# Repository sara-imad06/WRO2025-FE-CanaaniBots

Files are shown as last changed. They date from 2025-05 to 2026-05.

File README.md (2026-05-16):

# 📄 Table of contents
### [Our journey](#our-journey)
### [Our plan and Strategy](/our_plan_and_strategy.md)
### [Hardware documentation](/schemes/README.md)
### [Software documentation](/src/README.md)
### [Videos](/video/video.md)
### [Team Photos](/t-photos/)
### [Vehicle Photos](/v-photos/)

## The team yy
From Palestine, we are CanaaniBots — a team of three passionate young engineers and a supportive coach. After a year of competing together in WRO, trying out categories like Innovators and Future Engineers. This year, we're thrilled to return to the Future Engineers challenge once again!

>Members

- **Sara Abdou** from [Birzeit University](https://www.birzeit.edu/en) - Department of Electrical and Computer Engineering, Birzeit UNI
  - imadsara117@gmail.com
- **Rama Najjar** from [Birzeit University](https://www.birzeit.edu/en) - Department of Mechanical and Mechatronics Engineering, Birzeit UNI
  - ramanajjar25@gmail.com
- **Sadeel Taleeb** from [Birzeit University](https://www.birzeit.edu/en) - Department of Electrical and Computer Engineering, Birzeit UNI
  - sadeeltaleeb4@gmail.com

>Coach

- **Eng. Ahmad AbuBaker** - TA at the Mechanical and Mechatronics Engineering Department, Birzeit UNI,[Birzeit University](https://www.birzeit.edu/en/study/academic-departments/mmed)
  - ahmadabubaker199@gmail.com

## Past experiences
Over the past few years, our team has gained a wide range of skills and hands-on experience through continuous work in robotics projects and challenges. These experiences provided us with a strong foundation that we were able to carry into the Future Engineers category, several of our previous learnings remained valuable, such as:
Familiarity with various sensors, including gyroscope and ultrasonic sensors, as well as car steering mechanisms

  - Programming experience, including building our own frameworks
  - Developing visual debugging systems to test and refine our code
  - Hands-on experience with microcontrollers such as Raspberry Pi and Arduino
  - A solid background in working with different programming languages, sensors, and motors
  - Experience using OpenCV libraries for image processing and computer vision

## What the Robot Taught Us
Designing our robot was more than just building hardware—it was a full-on engineering adventure. Every challenge we faced pushed us to learn new tools, experiment with ideas, and grow as a team. From the first sketch to the final test run, the journey was packed with hands-on learning and exciting discoveries, Here are some of the key skills and experiences we gained:
  - Gained experience in mechanical design (learned how to use SolidWorks to design a functional mechanical differential) and prototyping using 3D modeling tools
  - We learned how to design electronic components using Fritzing
  - Explored and implemented advanced steering and turning systems
  - Integrated and calibrated various sensors to ensure accurate and stable robot behavior
  - Practiced debugging techniques and iterative testing to refine performance
  - Improved teamwork, time management, and project planning through collaboration

## Our first design
At first, our initial design was based on a [pre-made metal frame car](https://technolab.ps/detail/471), which included a metal base plate, two additional smaller base parts, a steering system, and four good-quality wheels. We did not rely on the original frame as it was; the main goal of using it was to speed up the design process. We modified it directly using custom parts that we designed and 3D printed, in order to implement the plan we had in mind more accurately and in a way that meets the project’s requirements.

The design phases of the robot were diverse and multi-staged, involving the design of new parts tailored to each stage of the robot’s mechanical development. The design was not static; it evolved continuously based on the requirements of each phase. We also conducted accuracy tests for the robot at each step, according to the strategy we had previously established, to ensure the desired performance and guide adjustments effectively.

All of these stages and modifications were documented in detail in the Hardware Documentation, serving as a clear and comprehensive reference for our work.

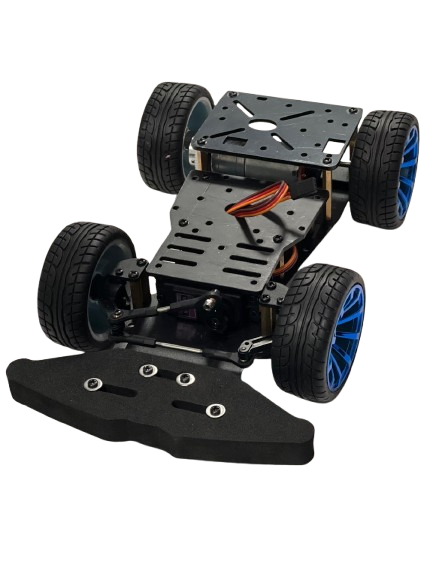
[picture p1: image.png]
pre-made metal frame car
  

## The final design

## Teamwork
We had weekly meetings with our coach to review our progress and make sure we were heading in the right direction. These sessions were essential for reflecting on what we had accomplished, discussing what needed improvement, and going through our documentation to keep everything organized and clear.

Our work was mainly divided into two main parts: mechanical and programming. Each of us focused more on one area depending on our strengths, but we made it a point to collaborate and support each other in both. If someone working on the mechanical side needed help with code, or someone on the programming side needed input on a physical design element, we’d jump in and figure it out together.

Just like our individual team meetings, these coach sessions helped us stay aligned, keep our momentum, and maintain a strong sense of shared responsibility for the entire project.

# Conclusion

# Special thanks
Special thanks to 'Kaksh' for helping us get the components and letting us use the Interface Lab 😊 Your support truly made a difference!
We also extend our heartfelt thanks to Al-Nabali & Al-Faris Co. for their generous financial support and continuous encouragement of our team.

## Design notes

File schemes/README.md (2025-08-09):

# Hardware documentation 
The robot consists of a wide variety of sensors, motors, and two processing units: a Raspberry Pi 5 and an Arduino Mega. The base is built on a 4WD RC Smart Car Robot Chassis with ann MG996R metal servo and bearing kit, which has been heavily modified to suit our project's requirements. These modifications include custom 3D-printed parts, such as a dedicated camera holder and custom spacers, as well as the replacement of several original components to improve stability, wiring, and sensor integration. All engineering modifications are thoroughly documented and clearly illustrated in the guide provided below.

## List of components
We installed a lot of sensors and other components on the car, here is a list of each of them with a link and some additional notes:
- **Base car** [4WD RC Smart Car Robot Chassis](https://technolab.ps/detail/471)
  - originally 248 x 146 mm, 690 g 695.7 g (including DC and servo motor)
- **Steering servo** [MG996R Metal Servo Bearing Kit](https://technolab.ps/detail/471)
- **DC motor** [DC Gear Motor with Encoder](https://roboticx.ps/product/dc-gear-motor-with-encoder/)
  -  Operating voltage 6V, torque 10 kg*cm max power 3.2A, 210 RPM, 341.2 pulse-per-revolution encoder
- **Single Board Computer** [Raspberry Pi 5 4GB](https://roboticx.ps/product/raspberry-pi-5/?asp_highlight=raspberry&p_asid=3)
  - Operating voltage 5V/5A USB-C, 4 USB ports, 40 pins
- **Microcontroller Arduino Mega 2560** [arduino](https://roboticx.ps/product/arduino-mega-2560-r3-china/)
  - Operating voltage 7-12V, 54 Digital I/O Pins (14 PWM outputs)- 16 Analog Inputs, dimensions: 101.5 x 53.3 mm
- **Motor driver** [L298N](https://roboticx.ps/product/dual-motor-controller-module-l298n/)
  - Max Drive current 2A, control voltage 4.5~5.5V
- **Battery**
  - Bundled with car, 4.2V, 5000mAh,Lithium, [Lithium Ion Battery](https://roboticx.ps/product/lithium-ion-battery-18650-cell-5000mah/)
- **Lithium Battery Charger Module**
  - Maximum current can be 5A , Output voltage 5V
- **Power switch** [SPST](https://roboticx.ps/product/rocker-switch-on-off-spst/)
- **Laser sensor x3** [VL53L0XV2 Laser](https://roboticx.ps/product/vl53l0xv2-laser-ranging-sensor-time-of-flight-tof/)
  - Dimensions 25 x 10 x 4 mm, 50mm – 1.2m range (default mode), 50mm – 2.2m range (long range mode), frequency 5-33 Hz, accuracy ±2cm ,3.3V
- **Camera** [Raspberry Pi Camera Module V2](https://roboticx.ps/product/raspberry-pi-camera-module/?asp_highlight=raspberry&p_asid=3)
  - No built-in color detection algorithm, field of View: 62.2° horizontal 48.8° vertical, up to 90 fps
- **IMU** [GY-BN008X](https://technolab.ps/products?search=bno)
  - Inertial Measurement Unit (IMU) BNO085 – operates at 3.3V with a gyro drift of about 0.5°/min and a dynamic rotation error of approximately 4.5°

## Sensors and motors communication protocols
The different communication protocols used between the components of the robot and their hierarchy:
- Computer
  - Raspberry Pi `SSH & VNC & micro-HDMI `
    - Ardunio Maga `USB `
      - DC Motor with endcoder `Interrupt`
      - Motor driver `PWM` 2x`Digital`
      - Servo `PWM`
      - 3x VL53L0X Sensor `I2C` + `Digital Output (XSHUT)`
  - Camera `CSI-2`

## Design and 3D Printing Of Parts and Assembly Instructions
All parts were specifically designed for the competition using SolidWorks and printed on Qidi i-Fast, Flsun V400, and Flashforge Adventurer 4 Pro printers using a slicer. The files were exported in (.stl) format for 3D printing, and the material used was PLA, The Flashforge Adventurer 4 Pro was mainly used for testing parts, as its print quality was not sufficient for final components. Once the designs were confirmed through testing, the Qidi i-Fast and Flsun V400 were used to print the final parts due to their higher speed and accuracy. You can view the designs of all parts in SLDASM and SLDPRT formats [here](/models/Solid_Works_3D_Drawings),we drilled and adjusted all the parts ourselves in the engineering workshops at the university.

### 1. Level one: Initial Kit-Based Structure and Custom Stage Planning
We started the mechanical build using individual parts from a kit, which included a steering system, a servo motor, and a DC motor. These components were assembled to create a basic driving platform suitable for the project’s initial requirements. Only the first stage of the kit was used, as it provided the base needed for steering and driving tests. The second stage was excluded. 

After initial assembly and testing, we decided to design a complete custom robot structure that better fit the competition dimensions and the hardware requirements. The first concept design was sketched directly on a photo of the assembled parts to visualize the planned structure. The design features a three-stage stacked layout, with all stages planned for 3D printing and optimized for height and component placement.

The first stage, reused from the kit, holds the servo motor and steering system at the front and the DC motor at the rear. The battery pack was placed in the center of this stage to keep the center of mass low, which improves traction between the wheels and the mat and increases stability during movement. This decision was based on advice from our coach, who recommended placing heavier components closer to the ground.

The second stage is designed to hold the Arduino Mega, the motor driver, and three distance sensors — one at the front, one on the left, and one on the right. The sketch originally labeled these as ultrasonic sensors, but they were later replaced with laser sensors after design finalization. This stage also includes space for organized cable routing and clean sensor alignment.

The third stage is reserved for the Raspberry Pi, which was placed at the top of the robot due to its higher heat output compared to the other components. Positioning it on the upper stage improves passive cooling. The design also includes a camera mount fixed to the front of the first stage, providing a stable and forward-facing view for image capture.
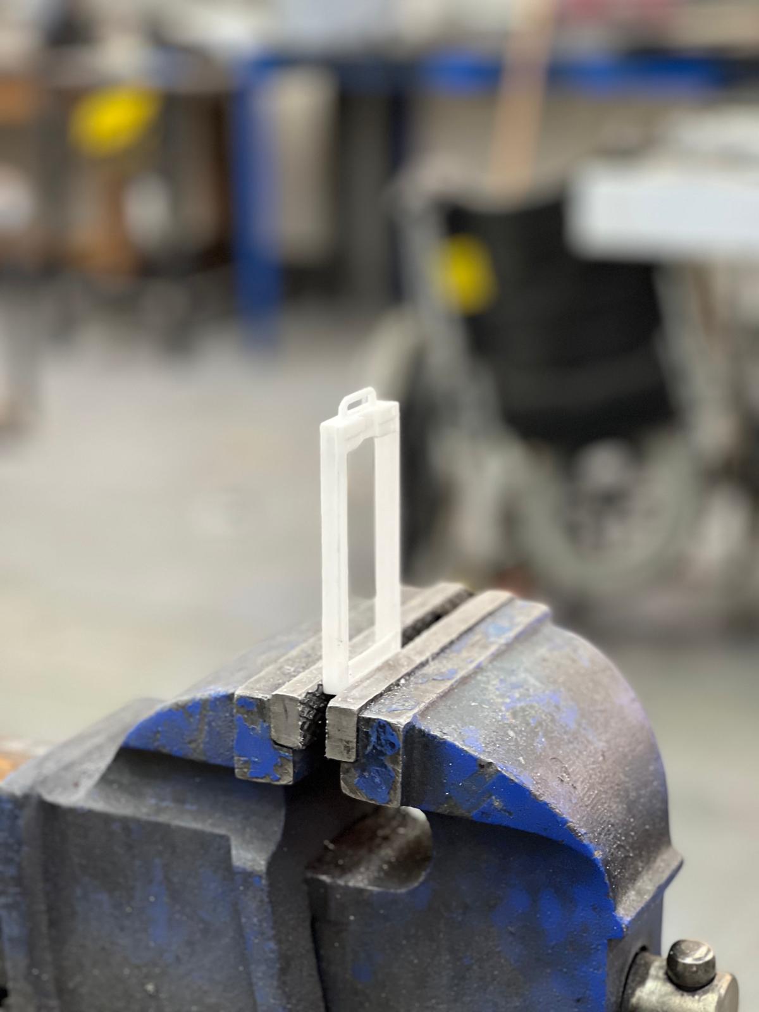
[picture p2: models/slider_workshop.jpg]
Slider


### 2. Level two: Mechanical Calibration for Straight-Line Stability
At this stage, the focus shifted to calibrating the robot’s mechanical movement to ensure it drives in a perfectly straight line without deviation. To achieve this, we designed and manufactured a set of calibration tools consisting of pen holders, created using SolidWorks and printed in PLA using 3D printers. These holders were mounted at the front and rear of the robot chassis and used as a simple tool to verify mechanical alignment.

Each holder includes a vertical opening designed to securely hold a pen. When the robot is placed on a flat surface and moves forward, both pens draw lines. The goal is for the two lines to perfectly overlap, which confirms that the robot is moving in a straight line. If there is any separation or misalignment between the lines, it indicates a deviation in the robot’s path. In such cases, we measured the offset and documented it, allowing us to later apply software-based corrections without the need for mechanical redesign.

During testing, we encountered an issue where the pen openings were too tight, preventing the pens from fitting properly. To solve this, we manually widened the holes using drilling tools in the university’s engineering workshops. This adjustment ensured the pens fit correctly and that the calibration tool functioned reliably, producing consistent and accurate results.

### 3. Level three:

### 4. Level four: 

### 5. Level five:

## Assembly
We encountered several challenges during the assembly and planning process, but we are very proud of the work we have accomplished. If you have any questions or encounter any issues, please don't hesitate to contact us at ramanajjar25@gmail.com(Rama) or ahmadabubaker199@gmail.com(Ahmad) through any preferred method.

## Wiring diagrams and details
### 1. Adjusting the servo motor angle  
[Wiring](/schemes/wiring_1.fzz)

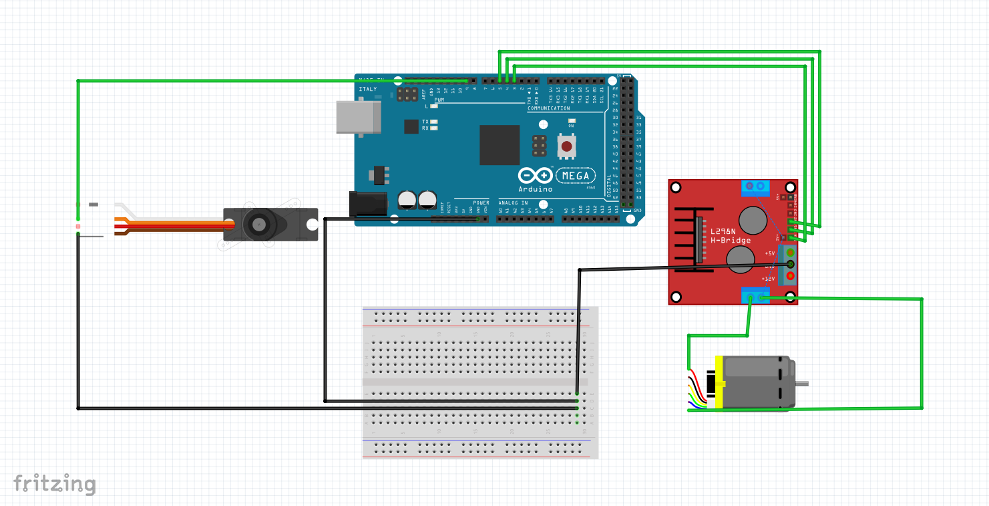
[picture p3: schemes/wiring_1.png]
Stage 1


#### Wiring details at this stage
**DC Motor via L298N Module**  
(Connected to pins 3, 4, and 5)  
L298N to Arduino Mega:
- IN1 → Pin 4 (controls motor direction)
- IN2 → Pin 5 (controls motor direction)
- ENA → Pin 3 (PWM pin, controls motor speed)

L298N Power:
- OUT1 & OUT2 → Connect to DC motor wires
- 12V / VCC → Connect to external power supply (6V–12V battery)
- GND → Connect to Arduino GND
- 5V (if jumper is present) → Optional; powers logic (you can use it if your battery is strong enough)

---
**Servo Motor (Steering)**  
(Connected to pin 9)  
Servo Motor to Arduino Mega:
- Signal (usually orange or yellow) → Pin 9
- VCC (red) → External 5V–6V power source
- GND (brown/black) → Connect to common GND with Arduino

Note: Servo motors need a separate power supply if they draw significant current. Always connect the grounds together (Arduino GND and power source GND).

---
### 2. Connecting Arduino Mega with DC Motor Encoder and Servo Motor 
[Wiring diagram](/schemes/test_1_wiring.fzz)

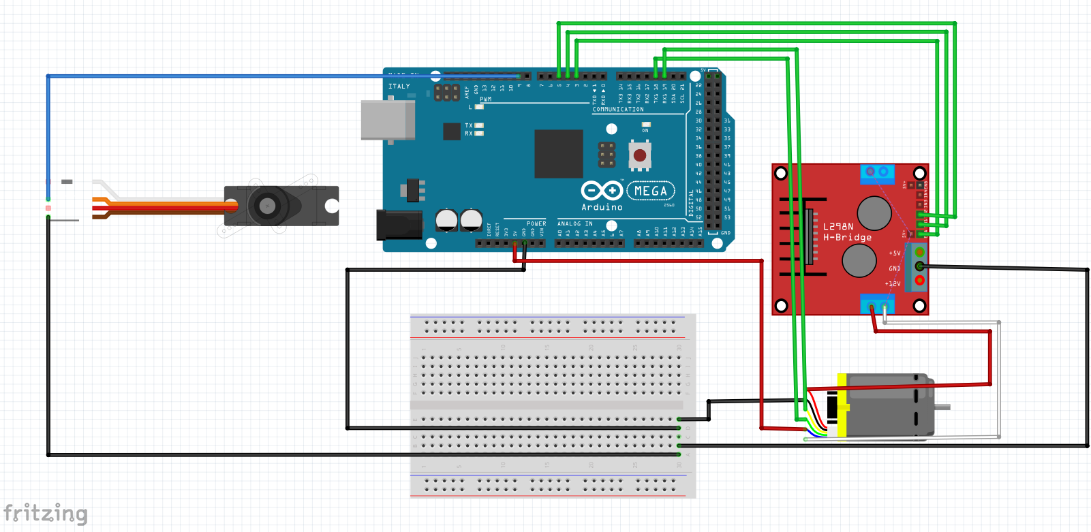
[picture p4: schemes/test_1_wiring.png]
wiring


#### Wiring details at this stage
**L298N Motor Driver to Arduino Mega**
- OUT1 → Red wire of the DC motor
- OUT2 → White wire of the DC motor
- ENA → Pin 3 on Arduino Mega (PWM control)
- IN1 → Pin 4 on Arduino Mega
- IN2 → Pin 5 on Arduino Mega
- GND → GND (to Arduino GND and battery GND)
- 12V → External power (6V–12V battery)

---
**DC Motor Encoder**
- Green (A signal) → Arduino Mega Pin 18 (Interrupt)
- Yellow (B signal) → Arduino Mega Pin 19 (Interrupt)
- Blue (VCC) → Arduino 5V
- Black (GND) → Arduino GND

---
**Servo Motor to Arduino Mega**
- Signal (Orange) → Pin 9 on Arduino Mega
- VCC (Red) → External 5V–6V power source 
- GND (Brown) → Common GND (Arduino GND + battery GND)

---
**Power Connections**
- DC Motor → Powered by external source (6V–12V) through L298N
- Servo Motor → Separate regulated 5V–6V source (e.g., 2S LiPo with voltage regulator)
- Arduino Mega → Powered via USB or VIN (7V–12V regulated input)

### 3. Connecting 3x VL53L0X Sensors and red LED
[Wiring diagram](/schemes/sensors_wiring.fzz)

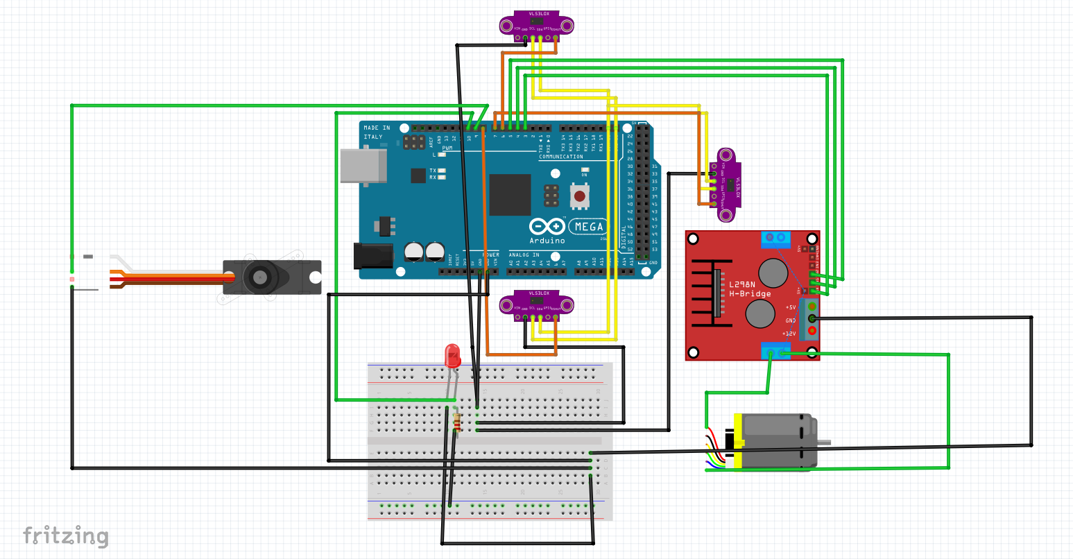
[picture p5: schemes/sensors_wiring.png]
wiring


#### Wiring details at this stage
**Left VL53L0X Sensor**
- VIN → 5V
- GND → GND
- SDA → Arduino Mega Pin 20
- SCL → Arduino Mega Pin 21
- XSHUT → Arduino Mega Pin 6
---
**Front VL53L0X Sensor**
- VIN → 5V
- GND → GND
- SDA → Arduino Mega Pin 20
- SCL → Arduino Mega Pin 21
- XSHUT → Arduino Mega Pin 7
---
**Right VL53L0X Sensor**
- VIN → 5V
- GND → GND
- SDA → Arduino Mega Pin 20
- SCL → Arduino Mega Pin 21
- XSHUT → Arduino Mega Pin 8
---
**Red LED**
- Anode (long leg) → Arduino Pin 10 (with a 220Ω resistor in series)
- Cathode (short leg) → GND (common ground with Arduino)

## Power
## Mechanical methods
workshop details will be here
## Conclusion

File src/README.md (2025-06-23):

# Software documentation 
This document aims to present all the software solutions we have developed—whether through experiments, testing, or iterative development—leading up to the final software implementation. It also outlines the logic and methodology we used to analyze and solve the project challenges by breaking them down into their simplest components.

The system relies primarily on the Raspberry Pi 5, which functions as the "brain" of the robot. It is mainly responsible for analyzing and processing images captured by the camera, utilizing Computer Vision (CV) techniques, as well as Machine Learning (ML) and Artificial Intelligence (AI) to enable the robot to make intelligent decisions based on visual and environmental data.

In parallel, the system includes an Arduino Mega, which serves as the main controller for all motor operations and directional control. It executes movement commands received from the Raspberry Pi and directly manages the DC motors, servos, and motor driver modules to ensure accurate and responsive navigation.

## Components and Connections Simulation
We designed and modified these parts to match the needs of our WRO project, using Fritzing based on our specific requirements. The design process was guided by our strategy of fully simulating all components, connections, and code before implementation. Therefore, creating these parts was an essential step in our plan to ensure a smooth transition from theoretical design to practical application[Parts](https://github.com/sara-imad06/WRO-Designed-Components.git),these parts were created as part of the software work to support the hardware work and make it easeir, and all components and their uses can be found in the Hardware Documentation.

## Visualizer 

## Programming computer & Code editor
This can be either a laptop or a PC. We tested everything on a laptop running Windows 11.We used Visual Studio Code [VScode](https://code.visualstudio.com/download), we used several extinstions like :[Python](https://marketplace.visualstudio.com/items?itemName=ms-python.python), [Ardunio](https://marketplace.visualstudio.com/items?itemName=lintangwisesa.arduino),[Ardunio](https://marketplace.visualstudio.com/items?itemName=moozzyk.Arduino), [Java](https://marketplace.visualstudio.com/items?itemName=SonderMX.java-kits)

You need to install Python on your device with a version that is compatible with your system. We also installed some specific Python libraries:
`pip install pyserial`<br>
`pip install numpy matplotlib`<br>

## Coding Langueges 
At the beginning of the development process, we used Java during the testing phase to experiment with and verify individual code segments. Once we confirmed that each part was working correctly, we assembled the [full code]() in C++, incorporating some C-based syntax and functions, as it is faster and easier to work with when controlling the Arduino and its motors. 

For the Raspberry Pi 5, the code was written in Python, which is the most suitable and widely supported language for working with cameras and communicating with the Pi. To enable communication between the Raspberry Pi (running Python) and the Arduino (running C++), we implemented a [communication code]() over a USB serial connection.

## Arduino Mega
The [Arduino Integrated Development Environment](https://www.arduino.cc/en/software/)  was our choice to develop our first stage (testing code) files were in**file.ino** extinstion. In later stages we moved into VS code.

## Raspberry Pi 5
## Testing Code 
At this stage, we developed an experimental code based on the basic wiring, with the main goal of testing all wheels, motors, and controllers. This stage was divided into three main parts:

### 1. Adjusting the servo motor angle
During this process, the center angle was set to 90 degrees, with a deviation range of ±10 degrees  
[Code](/src/servo_test_code.java)
``` Java
int centerAngle = 90;
int maxDeviation = 10; 

 void turn(int degreesFromCenter) {
    degreesFromCenter = constrain(degreesFromCenter, -maxDeviation, maxDeviation);
    servo.write(centerAngle + degreesFromCenter);
```

#### Classes  
`DCMotor`  
To control the motor speed and direction.

`Steering`  
To control the servo angle with limits.  
`Steering` is currently empty — to add automatic or manual control later.

---

### 2. Working on it simultaneously with the mechanical aspect
The DC motor runs continuously forward, while the servo automatically turns every 5 seconds in a loop: Left → Center → Right → repeat.  
[Code](/src/test.java)

#### Functions  
`setup()`  
Initializes motor and servo pins, starts forward movement, centers the servo, and begins Serial communication.

`loop()`  
Repeatedly changes the steering direction every 5 seconds and prints the current state to the Serial Monitor with center angle = 90, Max to Right = 125, Max to Left = 55.

### 3.
### 4. 

## Open challenge
## Obstacle challenge
## Framework - functions

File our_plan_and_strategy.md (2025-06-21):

# Plan and Strategy
This whole experience felt like a big adventure full of late nights, questions, research, mistakes, and wins. We're really thankful for such a lovely opportunity!
## Principles
- **Be accurate**
- **Be creative**
- **Google your smartest teammate :)**
- **Ask everyone**
- **Be Brave and Open to try**

  ## Ideas
- We excluded the ultrasonic sensor because it takes a long time to respond, making it relatively slow and less accurate. Additionally, when turning at a 90-degree angle, it may return incorrect values, as it reports the nearest distance rather than the parallel one.
- We did not use the color sensor because its readings change with varying lighting conditions, and it needs to be very close to the object to provide accurate values.
- We opted for sensors that rely on laser light transmission technology because they offer relatively higher accuracy,and they provide an approximate measurement of the distance between the robot and the opposing objects in an almost parallel alignment.
- Speed is important, but what matters more is accomplishing the required task with high accuracy first, and then increasing the speed.
- Mechanical calibration is indeed very important; ensuring minimal deviation from a straight path is essential.
- All sensors collect data to accurately determine the robot's position; the key to the solution always lies in measuring distances and pinpointing the robot's location.
- A strong framework is incredibly valuable, it significantly simplifies the process of tackling challenges.

## Strategy

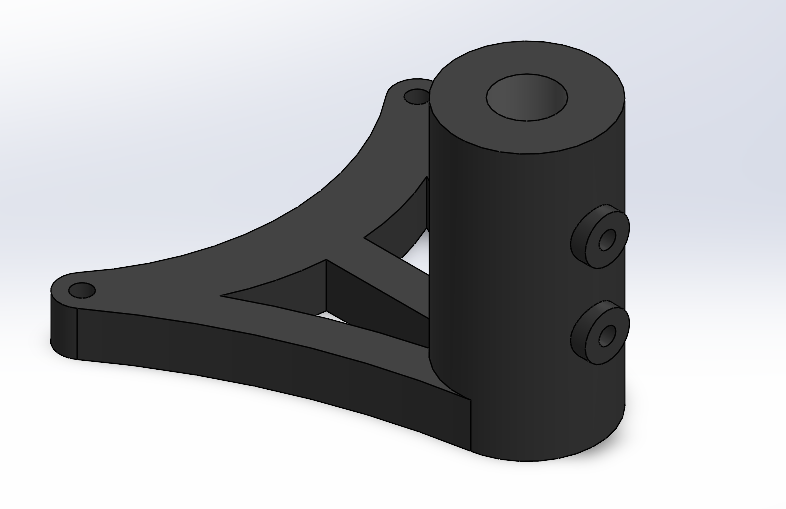
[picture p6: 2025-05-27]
models/Front Pen Holder ISO.png

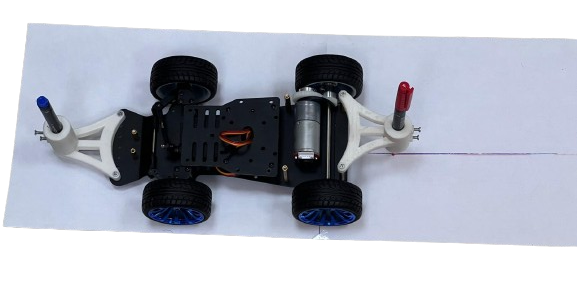
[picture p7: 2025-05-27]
models/stage_1.png

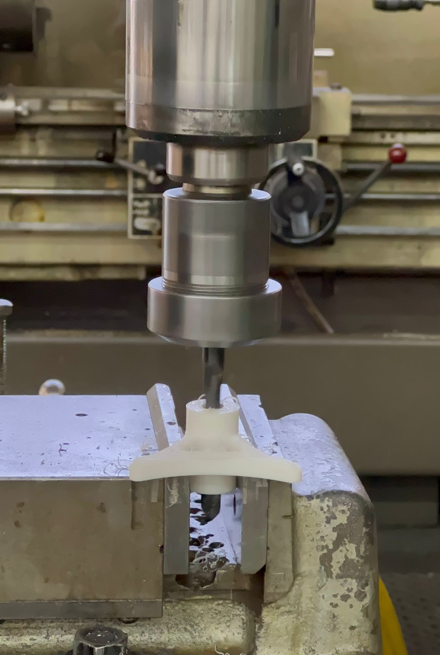
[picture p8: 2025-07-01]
models/Workshop 2.jpg

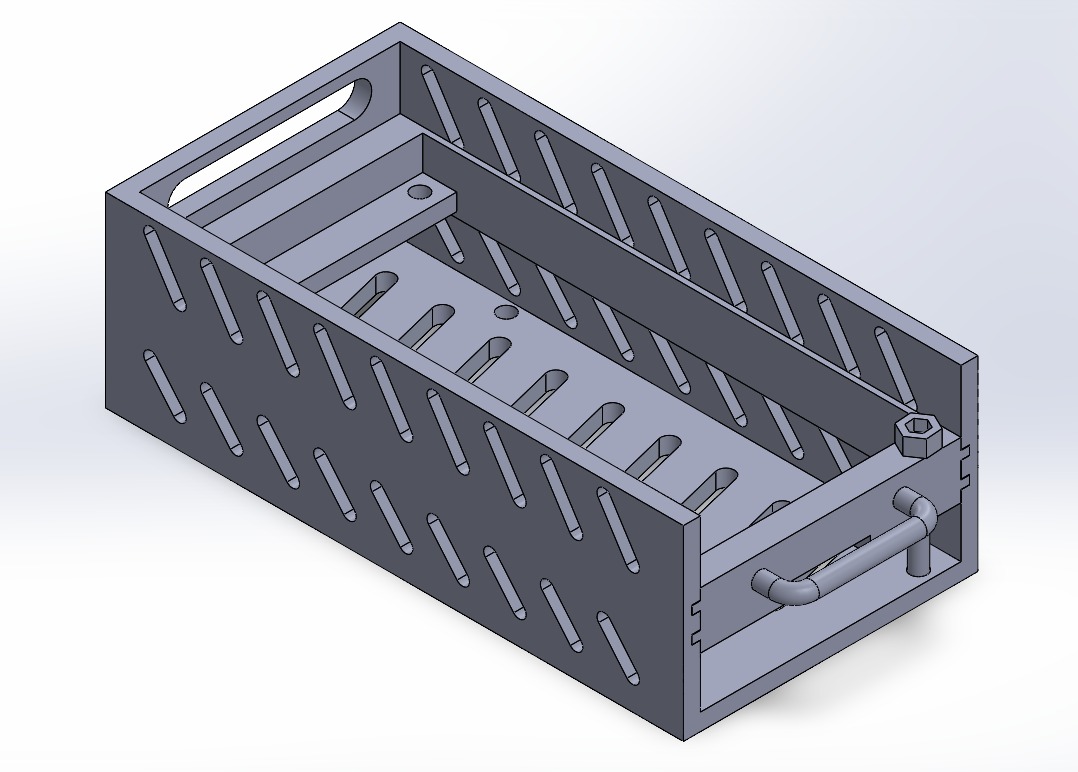
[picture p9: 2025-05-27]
models/Slider.jpg

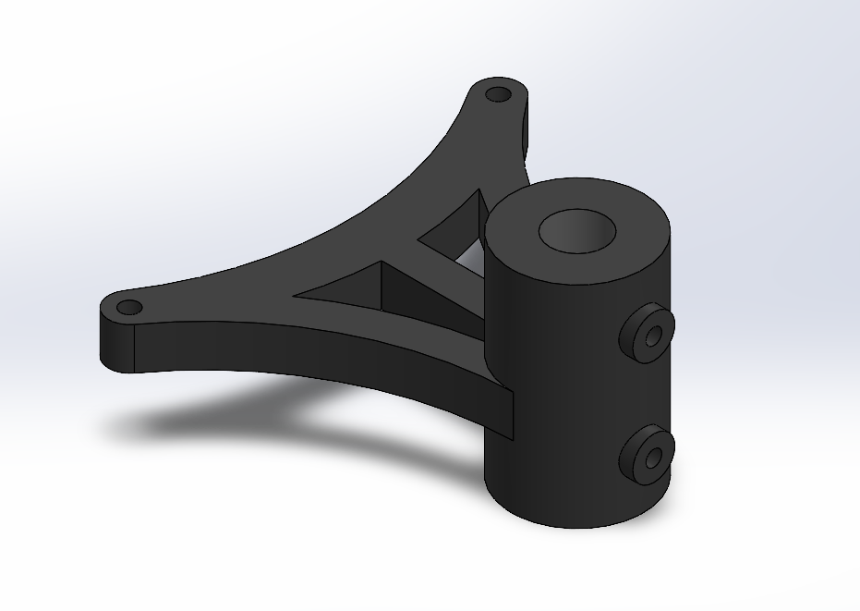
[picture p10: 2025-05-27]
models/Rear Pen Holder ISO.png

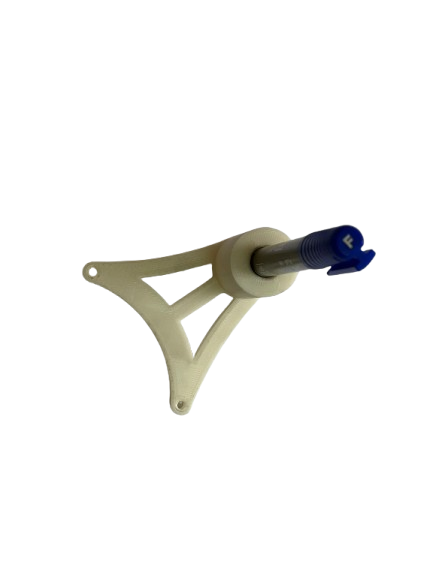
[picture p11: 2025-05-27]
models/pin_holder.png

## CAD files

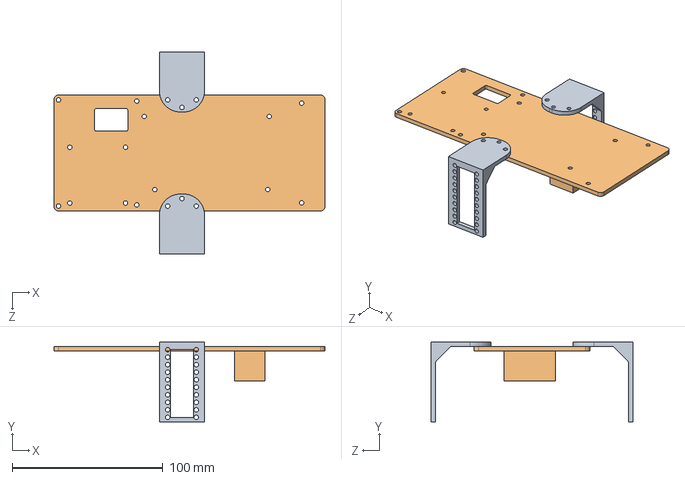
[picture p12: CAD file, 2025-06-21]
models/Solid_Works_3D_Drawings/VOF Assem.SLDASM
180.0 x 53.0 x 134.0 mm
Stage 2 base
TOF holder x 2

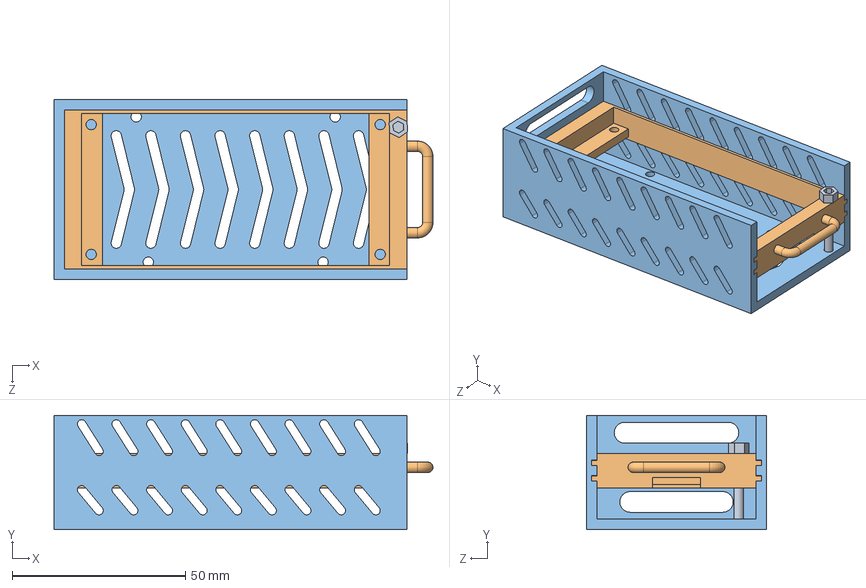
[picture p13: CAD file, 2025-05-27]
models/Solid_Works_3D_Drawings/Assem.SLDASM
109.5 x 33.0 x 52.0 mm
base
slotded cabin
screw

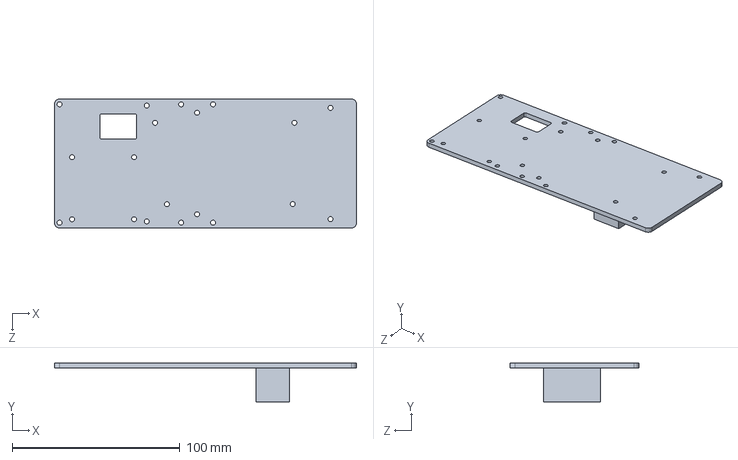
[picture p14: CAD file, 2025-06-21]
models/Solid_Works_3D_Drawings/Stage 2 base.SLDPRT
180.0 x 23.0 x 77.0 mm

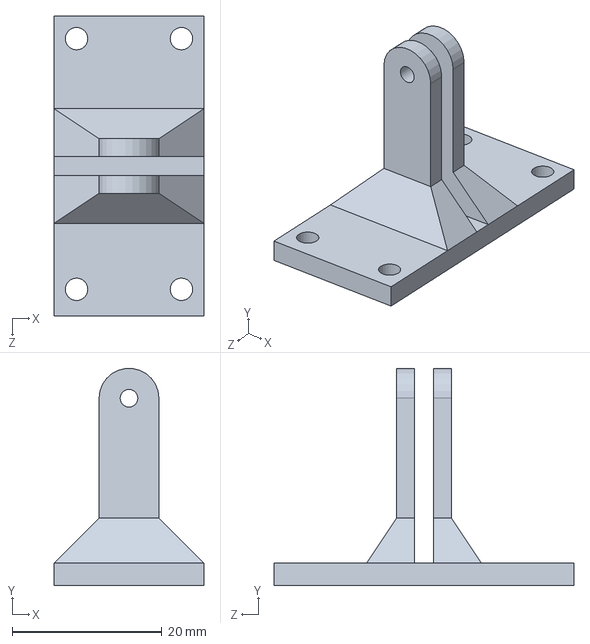
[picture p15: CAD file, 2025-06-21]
models/Solid_Works_3D_Drawings/camera Top holder.SLDPRT
20.0 x 29.0 x 40.0 mm

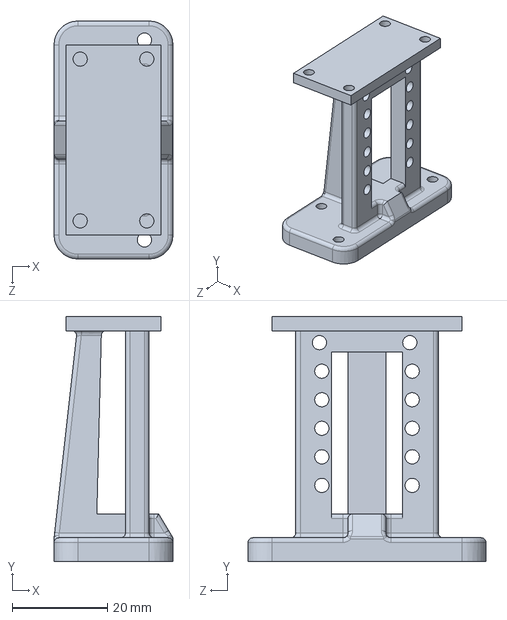
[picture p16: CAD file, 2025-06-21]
models/Solid_Works_3D_Drawings/camera and front TOF base holder.SLDPRT
25.0 x 51.5 x 50.0 mm

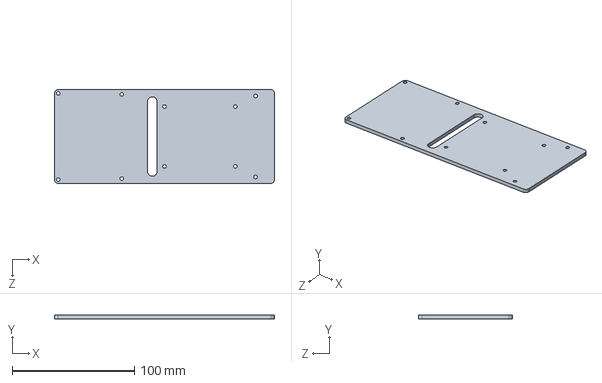
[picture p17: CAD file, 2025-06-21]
models/Solid_Works_3D_Drawings/Stage 3 base.SLDPRT
180.0 x 3.00 x 77.0 mm

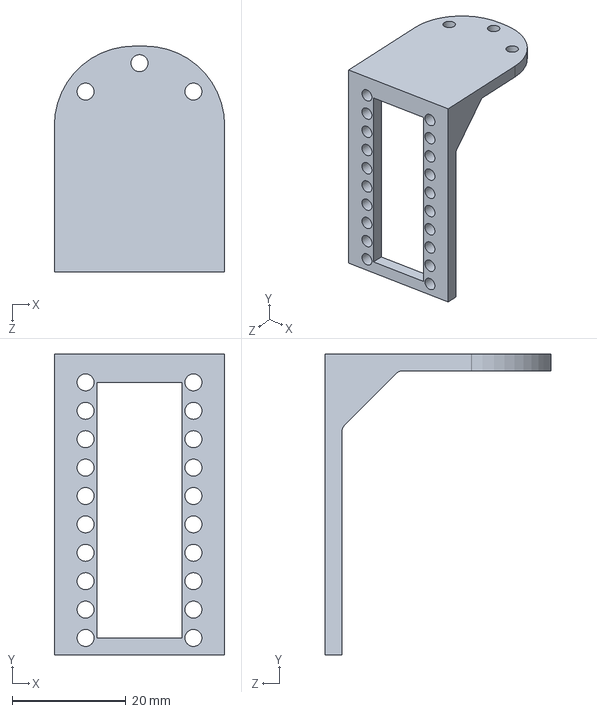
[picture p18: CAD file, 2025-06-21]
models/Solid_Works_3D_Drawings/TOF holder.SLDPRT
30.0 x 53.0 x 39.8 mm

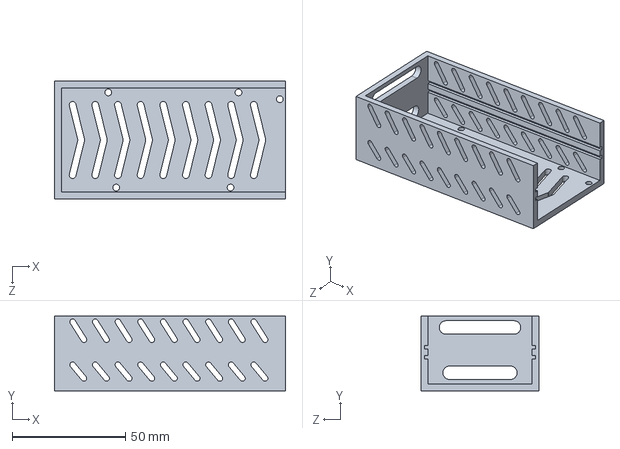
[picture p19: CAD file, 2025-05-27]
models/Solid_Works_3D_Drawings/base.SLDPRT
102.0 x 33.0 x 52.0 mm

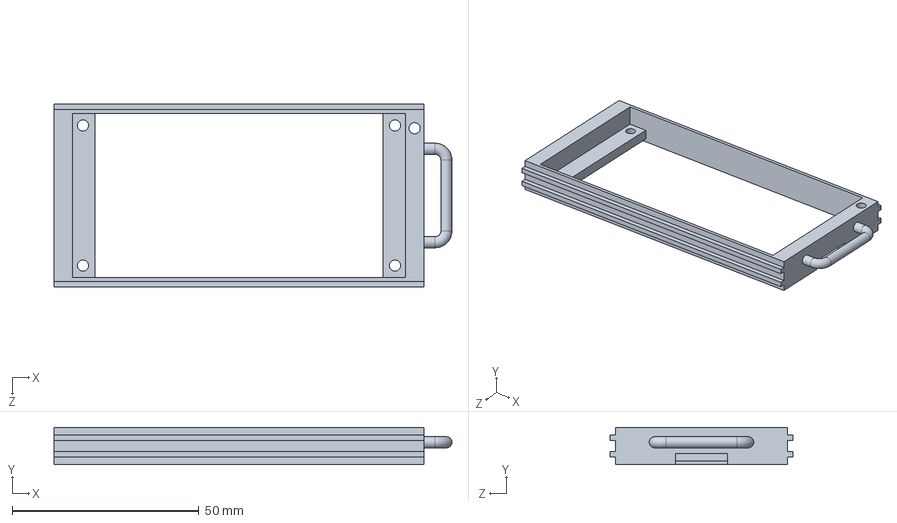
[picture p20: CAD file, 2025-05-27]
models/Solid_Works_3D_Drawings/slotded cabin.SLDPRT
106.5 x 10.0 x 49.0 mm

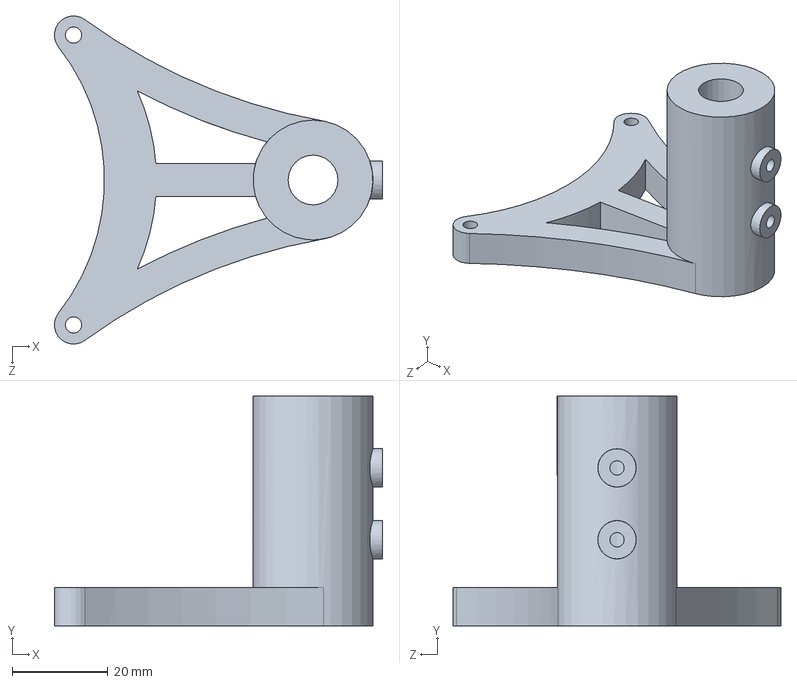
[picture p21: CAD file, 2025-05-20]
models/Solid_Works_3D_Drawings/Front Pen Holder.SLDPRT
68.5 x 48.0 x 68.5 mm

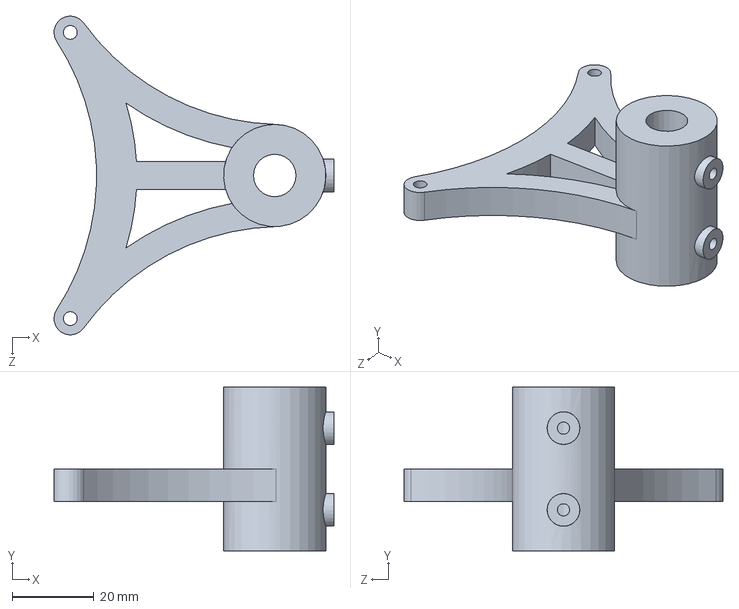
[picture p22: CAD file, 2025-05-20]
models/Solid_Works_3D_Drawings/Rear Pen Holder.SLDPRT
68.5 x 40.0 x 78.0 mm

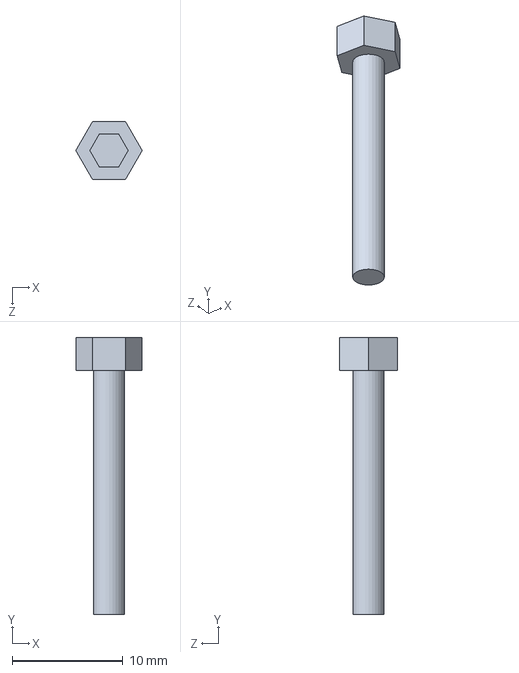
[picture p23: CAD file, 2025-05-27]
models/Solid_Works_3D_Drawings/screw.SLDPRT
6.00 x 25.0 x 5.20 mm

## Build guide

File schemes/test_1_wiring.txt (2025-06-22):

L298N Motor Driver to Arduino Mega
L298N Pin	Connect To
OUT1	Red wire of the DC motor
OUT2	White wire of the DC motor
ENA	Pin 3 on Arduino Mega (PWM control)
IN1	Pin 4 on Arduino Mega
IN2	Pin 5 on Arduino Mega
GND	GND (to Arduino GND and battery GND)
12V	External power (6V–12V battery)
5V	❌ Do NOT use (especially not for servo!)
________________________________________
 DC Motor Encoder 
Encoder Wire	Connect To
Green (A signal)	Arduino Mega Pin 18 (Interrupt)
Yellow (B signal)	Arduino Mega Pin 19 (Interrupt)
Blue (VCC)	Arduino 5V
Black (GND)	Arduino GND
________________________________________
 Servo Motor to Arduino Mega
Servo Wire	Connect To
Signal (Orange)	Pin 9 on Arduino Mega
VCC (Red)	⚠️ External 5V–6V power source (not Arduino)
GND (Brown)	Common GND (Arduino GND + battery GND)
Important: Don’t power the servo directly from the Arduino Mega — it doesn’t provide enough current. Use a battery pack or buck converter with shared ground.
________________________________________
 Power Connections
•	DC Motor → Powered by external source (6V–12V) through L298N
•	Servo Motor → Separate regulated 5V–6V source (e.g., 2S LiPo with voltage regulator)
•	Arduino Mega → Powered via USB or VIN (7V–12V regulated input)
________________________________________
Pins Summary (Arduino Mega)
Purpose	Pin
DC Motor ENA (PWM)	Pin 3
DC Motor IN1	Pin 4
DC Motor IN2	Pin 5
Servo Signal	Pin 9
Encoder A	Pin 18 (optional)
Encoder B	Pin 19 (optional)

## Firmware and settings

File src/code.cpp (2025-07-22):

#include <Wire.h>
#include <Servo.h>
#include <VL53L0X.h>
#include <Adafruit_BNO08x.h>

// ===== Motor pins =====
const int ENA = 3;    // PWM speed control pin for motor
const int IN1 = 4;    // Direction control pin 1
const int IN2 = 5;    // Direction control pin 2

// ===== Servo =====
const int servoPin = 9;   // Servo signal pin
Servo steeringServo;

// ===== Encoder =====
const int ENCODER_A = 2;  // Encoder A signal (interrupt)
volatile long encoderTicks = 0;
void encoderISR() { encoderTicks++; }

// ===== VL53L0X sensors =====
VL53L0X sensorFront, sensorLeft, sensorRight;
const int XSHUT_LEFT = 6;   // XSHUT pin for left sensor
const int XSHUT_FRONT = 7;  // XSHUT pin for front sensor
const int XSHUT_RIGHT = 8;  // XSHUT pin for right sensor

// ===== IMU =====
Adafruit_BNO08x bno = Adafruit_BNO08x();
float yaw = 0.0; // current yaw in degrees

// ===== Settings =====
const int angleStraight = 90;  // Servo angle for straight movement
const int maxSteer = 25;       // Maximum steering adjustment in degrees
const int normalSpeed = 180;   // PWM value for normal speed
const int slowSpeed = 120;     // PWM value for slow speed
const float TICKS_PER_CM = 16.7; // Encoder ticks per centimeter (calibrate!)
int drivingDirection = +1;    // +1 = CCW (turn left), -1 = CW (turn right)

// ===== Motor control functions =====
void motorForward(int pwm) {
  digitalWrite(IN1, LOW);
  digitalWrite(IN2, HIGH);
  analogWrite(ENA, pwm);
}

void motorBackward(int pwm) {
  digitalWrite(IN1, HIGH);
  digitalWrite(IN2, LOW);
  analogWrite(ENA, pwm);
}

void motorStop() {
  analogWrite(ENA, 0);
}

// ===== Encoder helper =====
void resetEncoder() {
  noInterrupts();
  encoderTicks = 0;
  interrupts();
}

// ===== IMU yaw reading =====
float getYaw() {
  sh2_SensorValue_t val;
  if (bno.getSensorEvent(&val)) {
    if (val.sensorId == SH2_GAME_ROTATION_VECTOR) {
      yaw = val.un.gameRotationVector.yaw * 180.0 / PI;
      if (yaw < 0) yaw += 360;
    }
  }
  return yaw;
}

// ===== VL53L0X initialization =====
void setupSensors() {
  pinMode(XSHUT_LEFT, OUTPUT);
  pinMode(XSHUT_FRONT, OUTPUT);
  pinMode(XSHUT_RIGHT, OUTPUT);

  // Reset all sensors
  digitalWrite(XSHUT_LEFT, LOW);
  digitalWrite(XSHUT_FRONT, LOW);
  digitalWrite(XSHUT_RIGHT, LOW);
  delay(10);

  // Initialize left sensor
  digitalWrite(XSHUT_LEFT, HIGH);
  delay(10);
  sensorLeft.init(true);
  sensorLeft.setAddress(0x30);

  // Initialize front sensor
  digitalWrite(XSHUT_FRONT, HIGH);
  delay(10);
  sensorFront.init(true);
  sensorFront.setAddress(0x31);

  // Initialize right sensor
  digitalWrite(XSHUT_RIGHT, HIGH);
  delay(10);
  sensorRight.init(true);
  sensorRight.setAddress(0x32);

  // Start continuous ranging
  sensorLeft.startContinuous();
  sensorFront.startContinuous();
  sensorRight.startContinuous();
}

// ===== Wall-following step =====
void wallFollowStep() {
  int distL = sensorLeft.readRangeContinuousMillimeters();
  int distF = sensorFront.readRangeContinuousMillimeters();
  int distR = sensorRight.readRangeContinuousMillimeters();

  // If obstacle is too close in front
  if (distF < 150) {
    motorBackward(slowSpeed);
    delay(300); // back up for 0.3 s
    if (distL > distR) steeringServo.write(angleStraight - maxSteer);
    else steeringServo.write(angleStraight + maxSteer);
    delay(300); // steer away briefly
    steeringServo.write(angleStraight);
    motorForward(normalSpeed);
  } else {
    // Normal wall following
    if (distL < 80) steeringServo.write(angleStraight + maxSteer);
    else if (distR < 80) steeringServo.write(angleStraight - maxSteer);
    else {
      int diff = distL - distR;
      int adjust = constrain(diff / 10, -maxSteer, maxSteer);
      steeringServo.write(angleStraight - adjust);
    }
    motorForward(normalSpeed);
  }
}

// ===== Drive forward a precise distance =====
void driveForwardCM(float cm) {
  resetEncoder();
  while (true) {
    long ticks;
    noInterrupts();
    ticks = encoderTicks;
    interrupts();
    if (ticks >= cm * TICKS_PER_CM) {
      motorStop();
      break;
    }
    wallFollowStep();
    delay(50);
  }
}

// ===== Turn to a specific absolute angle =====
void turnToAngle(float target) {
  if (drivingDirection == +1) { // CCW (turn left)
    steeringServo.write(angleStraight - maxSteer);
    motorForward(slowSpeed);
    while (true) {
      float current = getYaw();
      float error = target - current;
      if (error < 0) error += 360;
      if (error < 3) break;
      delay(20);
    }
  } else { // CW (turn right)
    steeringServo.write(angleStraight + maxSteer);
    motorForward(slowSpeed);
    while (true) {
      float current = getYaw();
      float error = current - target;
      if (error < 0) error += 360;
      if (error < 3) break;
      delay(20);
    }
  }
  motorStop();
  steeringServo.write(angleStraight);
}

// ===== Determine initial driving direction =====
void detectDrivingDirection() {
  int distL = sensorLeft.readRangeContinuousMillimeters();
  int distR = sensorRight.readRangeContinuousMillimeters();

  if (distL < 200) {
    // Wall on the left
    drivingDirection = +1; // CCW
    steeringServo.write(angleStraight - 30);
    motorForward(normalSpeed);
    delay(1000); // move diagonally for 1 s
    motorStop();
    steeringServo.write(angleStraight);
  } else if (distR < 200) {
    // Wall on the right
    drivingDirection = -1; // CW
    steeringServo.write(angleStraight + 30);
    motorForward(normalSpeed);
    delay(1000);
    motorStop();
    steeringServo.write(angleStraight);
  } else {
    // No nearby walls, move a bit and decide
    resetEncoder();
    while (true) {
      long ticks;
      noInterrupts();
      ticks = encoderTicks;
      interrupts();
      if (ticks >= 20 * TICKS_PER_CM) break;
      motorForward(normalSpeed);
      delay(50);
    }
    motorStop();
    if (sensorLeft.readRangeContinuousMillimeters() > sensorRight.readRangeContinuousMillimeters()) {
      drivingDirection = +1;
    } else {
      drivingDirection = -1;
    }
  }
}

// ===== Arduino setup =====
void setup() {
  Serial.begin(115200);

  pinMode(ENA, OUTPUT);
  pinMode(IN1, OUTPUT);
  pinMode(IN2, OUTPUT);

  steeringServo.attach(servoPin);
  steeringServo.write(angleStraight);

  pinMode(ENCODER_A, INPUT_PULLUP);
  attachInterrupt(digitalPinToInterrupt(ENCODER_A), encoderISR, RISING);

  Wire.begin();
  setupSensors();

  if (!bno.begin_I2C()) {
    Serial.println("IMU not found!");
    while (1);
  }
  bno.enableReport(SH2_GAME_ROTATION_VECTOR, 10);
  delay(100);

  getYaw();
  detectDrivingDirection();
  Serial.println("Ready to start open challenge!");
}

// ===== Main loop =====
void loop() {
  float targetYaw = getYaw();
  for (int i = 0; i < 12; i++) {
    // Go forward one section (100 cm)
    driveForwardCM(100);

    // Update target angle for next corner
    if (drivingDirection == +1) {
      targetYaw -= 90;
      if (targetYaw < 0) targetYaw += 360;
    } else {
      targetYaw += 90;
      if (targetYaw >= 360) targetYaw -= 360;
    }

    // Turn to new angle
    turnToAngle(targetYaw);
  }

  // After 3 laps, drive forward until front wall is ~150 mm
  while (true) {
    int distF = sensorFront.readRangeContinuousMillimeters();
    if (distF <= 150) {
      motorStop();
      break;
    }
    motorForward(normalSpeed);
    delay(50);
  }

  motorStop();
  while (true) delay(1000); // done
}

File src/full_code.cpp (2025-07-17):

#include <Servo.h>
#include <Wire.h>
#include <VL53L0X.h>

const int ENA = 3;
const int IN1 = 4;
const int IN2 = 5;

const int servoPin = 9;
Servo steeringServo;

// LED 
const int ledPin = 10;

// VL53L0X
VL53L0X sensorFront, sensorLeft, sensorRight;
const int XSHUT_LEFT = 6;
const int XSHUT_FRONT = 7;
const int XSHUT_RIGHT = 8;


int servoAngle = 90;

int normalSpeed = 255;  // med speed
int slowSpeed   = 100;  // high speed

void setupSensors() {
  pinMode(XSHUT_LEFT, OUTPUT);
  pinMode(XSHUT_FRONT, OUTPUT);
  pinMode(XSHUT_RIGHT, OUTPUT);

  digitalWrite(XSHUT_LEFT, LOW);
  digitalWrite(XSHUT_FRONT, LOW);
  digitalWrite(XSHUT_RIGHT, LOW);
  delay(10);

  digitalWrite(XSHUT_LEFT, HIGH);
  delay(10);
  sensorLeft.init(true);
  sensorLeft.setAddress(0x30);

  digitalWrite(XSHUT_FRONT, HIGH);
  delay(10);
  sensorFront.init(true);
  sensorFront.setAddress(0x31);

  digitalWrite(XSHUT_RIGHT, HIGH);
  delay(10);
  sensorRight.init(true);
  sensorRight.setAddress(0x32);

  sensorLeft.startContinuous();
  sensorFront.startContinuous();
  sensorRight.startContinuous();
}

void setup() {
  pinMode(ENA, OUTPUT);
  pinMode(IN1, OUTPUT);
  pinMode(IN2, OUTPUT);

  pinMode(ledPin, OUTPUT);
  digitalWrite(ledPin, LOW);

  steeringServo.attach(servoPin);
  steeringServo.write(servoAngle);

  Serial.begin(9600);
  Wire.begin();
  setupSensors();

  digitalWrite(IN1, LOW);
  digitalWrite(IN2, HIGH);
  analogWrite(ENA, normalSpeed);
}

void loop() {
  int distLeft  = sensorLeft.readRangeContinuousMillimeters();
  int distFront = sensorFront.readRangeContinuousMillimeters();
  int distRight = sensorRight.readRangeContinuousMillimeters();

  Serial.print("L: "); Serial.print(distLeft);
  Serial.print(" F: "); Serial.print(distFront);
  Serial.print(" R: "); Serial.println(distRight);

  // detact wall
  bool obstacle = (distFront < 150 || distLeft < 100 || distRight < 100);

  if (obstacle) {
    analogWrite(ENA, slowSpeed);
    digitalWrite(ledPin, HIGH);

    if (distFront < 150) {
      servoAngle = 110; // 
    } else if (distRight < 100) {
      servoAngle = 70;  // left
    } else if (distLeft < 100) {
      servoAngle = 110; // right
    }
  } else {
    analogWrite(ENA, normalSpeed);
    digitalWrite(ledPin, LOW);
    servoAngle = 90;
  }

  steeringServo.write(servoAngle);

  delay(10); 
}

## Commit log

2025-05-27 Rename Front Pin Holder ISO.png to Front_Pin_Holder_ISO.png
2025-05-28 Rename Rear Pin Holder.SLDPRT to Rear Pen Holder.SLDPRT
    [Rear Pen Holder.SLDPRT]
2025-05-28 Rename Rear Pin Holder ISO.png to Rear Pen Holder ISO.png
2025-05-28 Rename Front Pin Holder.SLDPRT to Front Pen Holder.SLDPRT
    [Front Pen Holder.SLDPRT]
2025-05-28 Rename Front Pin Holder ISO.png to Front Pen Holder ISO.png
2025-06-07 Software documentation Update
    [wiring_1.fzz]
2025-06-23 New stage - wiring
    [sensors_wiring.fzz]
